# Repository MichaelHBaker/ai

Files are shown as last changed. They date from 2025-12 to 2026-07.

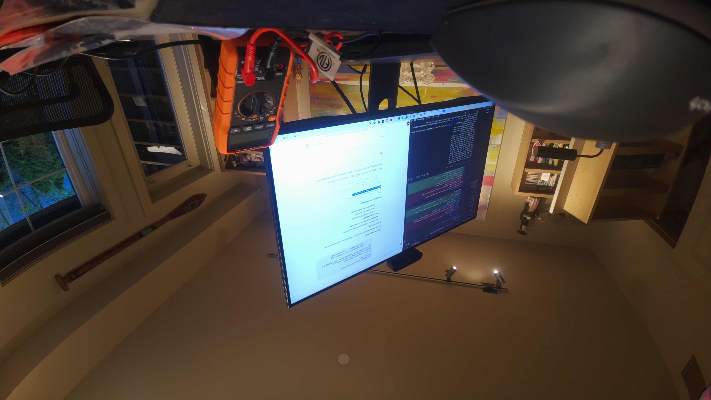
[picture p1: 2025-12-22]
test_image.jpg

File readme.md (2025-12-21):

# Autonomous Robot Learning Project

## Project Overview
12-month self-directed learning project to build an autonomous voice-controlled robot from scratch using only open-source software and Raspberry Pi hardware. Budget: $400 (actual: $462).

## Current Status
**Phase:** Phase 0 - Desktop Testing & Component Validation **IN PROGRESS** 🔄  
**Date:** December 20, 2024  
**Next Milestone:** Camera Module 3 connection and testing

### Recent Milestones
- ✅ **Dec 20, 2024:** Raspberry Pi OS installed, SSH configured, OpenCV 4.10.0 validated
- ✅ **Dec 20, 2024:** Pi 5 hardware validated with multimeter (3.3V and 5V rails healthy)
- ✅ **Dec 13, 2024:** Adafruit hardware delivered, Pi 5 assembled
- ✅ **Dec 12, 2024:** All hardware ordered (Adafruit + Amazon)
- ✅ **Nov 19, 2024:** HSV-bounded stereo vision algorithm completed
- ✅ **Nov 2024:** Phase 0 planning and component research completed
- ✅ **Oct 2024:** Project initiated, initial architecture decisions made

## Hardware - Phase 0 (Actual Purchases)

### Computing Platform - $144.04
**Ordered:** Adafruit Order #3595833-5617335047 (Dec 12, 2024)  
**Delivery:** UPS Next Day Air (Dec 13, 2024)

- **Raspberry Pi 5 8GB** (#5813) - $104.50
  - 2.4GHz quad-core ARM Cortex-A76
  - Dual native CSI camera ports
  - VideoCore VII GPU for CV acceleration
  - Selected over Pi 4 for 2-3x performance, dual CSI support
  
- **Official 27W USB-C Power Supply 5.1V 5A** (#5814) - $14.04
  - Desktop testing and development
  
- **Official Active Cooler** (#5815) - $13.50
  - Temperature-controlled, 1.4CFM airflow
  - Required for sustained CV workloads
  - Desktop testing: 39.5°C idle (without cooler installed yet)
  
- **Official Pi 5 Case + Fan** (#5816) - $12.00
  - Protective enclosure with integrated cooling

### Vision System - $82.40
**Ordered:** Adafruit Order #3595833-5617335047 (Dec 12, 2024)  
**Delivery:** UPS Next Day Air (Dec 13, 2024)

- **2x Raspberry Pi Camera Module 3 Wide** (#5658) - $77.00
  - 12MP Sony IMX708 sensor
  - 120° FOV (selected over 76° standard for obstacle detection)
  - Native CSI interface (5-15ms latency vs 30-50ms USB)
  - 40% less power than USB webcams
  - 3g weight vs 200g for USB alternatives
  
- **2x Pi 5 Camera Cable 200mm** (#5818) - $5.40
  - 22-pin 0.5mm to 15-pin 1mm FPC adapters
  - Enables dual native CSI stereo vision

**Architecture Decision:** CSI cameras selected over Logitech C920 USB webcams for:
- Direct GPU connection (lower latency)
- Native dual-camera support on Pi 5
- Lower power consumption (critical for battery operation)
- Lighter weight (6g vs 400g for two cameras)
- Cost savings ($83 vs $280 for USB alternative)

### Sensors & Electronics - $31.60
**Ordered:** Adafruit Order #3595833-5617335047 (Dec 12, 2024)  
**Delivery:** UPS Next Day Air (Dec 13, 2024)

- **3x HC-SR04 Ultrasonic Sensors** (#3942) - $11.85
  - 2-400cm range, ±3mm accuracy
  - 5V operation with 5V echo output
  - Includes 2x 10kΩ resistors per sensor
  
- **4-channel Logic Level Converter** (#757) - $3.95
  - BSS138 bidirectional converter
  - Protects Pi 5 GPIO (3.3V) from HC-SR04 echo (5V)
  - Selected over voltage dividers for cleaner breadboard
  
- **Premium Breadboard 830 tie points** (#239) - $5.95
- **Premium M-M Jumper Wires 20x3"** (#1956) - $1.95
- **Premium F-F Jumper Wires 20x3"** (#1951) - $1.95
- **Micro HDMI to HDMI Cable 1m** (#4302) - $11.81
  - Desktop monitor connection for development

**Bonuses (Free):**
- Adafruit KB2040 RP2040 Kee Boar Driver (#5302)
- PCB Coaster with Gold Adafruit Logo (#5719)

### Tools & Storage - $133.13
**Ordered:** Amazon (Dec 12, 2024)  
**Delivery:** Staggered (Dec 12-24, 2024)

- **Klein Tools MM420 Auto-Ranging Multimeter** - $64.98
  - Delivered: Dec 12, 2024
  - TRMS, 600V AC/DC, 10A current, 50MΩ resistance
  - Auto-ranging for efficient testing workflow
  - Critical for: voltage verification, current measurement, continuity testing
  - **Used:** Validated Pi 5 power rails (3.3V: 3.30V ✓, 5V: 4.93V ✓)
  
- **Anker PowerCore Essential 20000 PD** - $51.95
  - Delivers: Wednesday, Dec 17
  - 20,000mAh capacity, USB-C Power Delivery
  - 18W output (sufficient for Pi 5 + sensors)
  - 8-10 hour runtime estimate for autonomous operation
  - Selected over wall-only power for mobile robotics requirement
  
- **SanDisk Extreme 64GB microSDXC A2** - $16.20
  - Delivered: Dec 20, 2024
  - 170MB/s read, C10/U3/V30/4K/5K/A2 ratings
  - A2 performance class for faster app loading
  - **Used:** Raspberry Pi OS 64-bit installed successfully

### Phase 0 Budget Summary
- **Adafruit Subtotal:** $263.90
- **Adafruit Shipping (UPS Next Day):** $34.38
- **Adafruit Sales Tax:** $30.87
- **Adafruit Total:** $329.15
- **Amazon Total:** $133.13
- **Phase 0 Grand Total:** $462.28
- **Over Original $400 Budget:** $62.28

**Budget Variance Rationale:**
- Wide angle cameras: +$18.50 (120° FOV better for obstacle detection)
- Pi 5 upgrade: +$15.00 (2-3x performance, dual CSI native support)
- Professional multimeter: +$40.00 (vs basic model, auto-ranging saves time)
- Battery system: +$52.00 (essential for autonomous navigation)
- Expedited shipping: +$34.38 (immediate project start)

**Remaining for Phase 2 (Motors/Chassis):** -$62.28 (requires budget revision or simplified design)

## Phase 0 - Desktop Testing Plan

### Week 1: OS Installation & System Validation (Dec 13-20) ✅ COMPLETE
**Hardware arrived Dec 13, completed Dec 20:**
- ✅ Pi 5 hardware validation with multimeter (3.3V: 3.30V, 5V: 4.93V)
- ✅ OS installation (Raspberry Pi OS 64-bit via Raspberry Pi Imager)
- ✅ Headless SSH configuration (michael@robot.local)
- ✅ System updates (37 packages upgraded, including picamera2)
- ✅ Development environment installed (Python 3, OpenCV 4.10.0, picamera2 0.3.33)
- ✅ Library validation confirmed (OpenCV and picamera2 import successfully)

**Success Criteria: ALL MET**
- ✓ Power rails within spec (3.2-3.4V and 4.75-5.25V)
- ✓ Headless SSH operation working
- ✓ All required libraries installed and verified
- ✓ System temperature stable (39.5°C idle without active cooler)

### Week 2: Single Camera Validation (Dec 21-27) - IN PROGRESS
**Next steps:**
- [ ] Connect single Camera Module 3 Wide to CSI-0 port
- [ ] Test basic camera capture with picamera2
- [ ] Port HSV color filtering algorithm from iPhone work
- [ ] Validate CSI latency vs expected performance
- [ ] Install and test active cooler under CV workload
- [ ] Measure power consumption under camera + CV load
- [ ] Document GPIO pin mapping for future sensor integration

**Success Criteria:**
- HSV filtering running at 20-30fps on Pi 5
- Thermal stability under 70°C with active cooler
- Power consumption measured and documented

### Week 3: Stereo Vision Testing (Dec 28-Jan 3)
**Requires: Both cameras operational**
- [ ] Connect second Camera Module 3 Wide to CSI-1 port
- [ ] Implement stereo camera synchronization
- [ ] Calibrate stereo baseline (test 10cm, 15cm, 20cm spacing)
- [ ] Test depth perception with HSV filtering
- [ ] Validate frame alignment and timing
- [ ] Measure dual-camera power consumption

**Calibration Process:**
- [ ] Print checkerboard pattern from `/calibration/Checkerboard-A4-30mm-8x6.pdf`
- [ ] Capture 20-30 calibration images per camera at various angles/distances
- [ ] Store calibration images in `/calibration/calibration_images/`
- [ ] Calculate camera matrices using OpenCV `calibrateCamera()`
- [ ] Save camera matrices to `/calibration/camera_matrices/`
- [ ] Implement undistortion pipeline for 120° barrel distortion correction
- [ ] Validate reprojection error <0.5 pixels

**Success Criteria:**
- Synchronized stereo capture at 20-30fps
- Accurate depth estimation for obstacle detection
- Frame alignment within 5ms
- Camera calibration matrices calculated and saved

### Week 4: Ultrasonic Sensor Integration (Jan 4-10)
**Requires: Logic level converter + HC-SR04 sensors**
- [ ] Breadboard HC-SR04 sensor with logic level converter
- [ ] Test 5V→3.3V echo signal protection
- [ ] Verify distance measurement accuracy (2-400cm range)
- [ ] Add second and third sensors (left/center/right array)
- [ ] Measure sensor power consumption
- [ ] Test sensor + camera combined operation

**Success Criteria:**
- ±3mm accuracy across full 2-400cm range
- No GPIO damage from 5V echo signals
- Reliable multi-sensor operation

### Week 5: Power System Testing (Jan 11-17)
**Requires: Anker power bank (arrived Dec 17)**
- [ ] Measure total system power draw (Pi + cameras + sensors)
- [ ] Test battery runtime under realistic CV workload
- [ ] Validate 8-10 hour runtime estimate
- [ ] Document power consumption profile for chassis design
- [ ] Test battery charging while operating (if needed)

**Success Criteria:**
- Actual runtime within 20% of estimate
- No power-related crashes or brownouts
- Power budget documented for Phase 1 planning

## Software Architecture

### Development Environment (Installed Dec 20, 2024)
- **OS:** Raspberry Pi OS 64-bit (Debian Trixie base)
- **Python:** 3.11.x (default system Python)
- **OpenCV:** 4.10.0 (python3-opencv package)
- **Camera Library:** picamera2 0.3.33 (python3-picamera2 package)
- **Package Manager:** pip 25.1.1
- **Access Method:** Headless SSH (michael@robot.local)

### Workflow
- **VS Code Claude:** Code writing, file editing, debugging
- **Web Claude:** Architecture, research, session documentation
- **Version Control:** Git with session-based commits
- **Testing:** Desktop environment, Pi 5 powered on desk

### Repository Structure
```
ai/
├── README.md                 # This file (project overview and documentation)
├── session_notes.md          # Chronological session history with decisions
├── calibration/              # Camera calibration patterns and artifacts
│   ├── Checkerboard-A4-30mm-8x6.pdf  # Calibration pattern for printing
│   ├── camera_matrices/      # Computed camera matrices (future)
│   └── calibration_images/   # Captured calibration images (future)
├── src/                      # Source code
│   ├── vision/              # Computer vision algorithms
│   │   └── hsv_filter.py    # HSV color space filtering (to be ported)
│   ├── sensors/             # Sensor interfaces
│   │   └── ultrasonic.py    # HC-SR04 distance sensing (to be developed)
│   └── tests/               # Component validation tests
├── docs/                     # Additional documentation
│   ├── datasheets/          # Component datasheets and references
│   └── architecture/        # System architecture diagrams
└── hardware/                 # Hardware designs (Phase 1)
    ├── chassis/             # Chassis CAD files (future)
    └── schematics/          # Circuit diagrams and wiring (future)
```

## Key Technical Decisions

### 1. Raspberry Pi 5 8GB over Pi 4 8GB
**Decision Date:** December 12, 2024  
**Cost Delta:** +$15 (vs Pi 4)

**Rationale:**
- **Performance:** 2-3x faster CPU (ARM Cortex-A76 vs A72)
- **Vision Architecture:** Dual native CSI ports (vs single on Pi 4)
- **AI Acceleration:** 2x faster inference for future ML models
- **Thermal Parity:** Both Pi 4 and Pi 5 require active cooling for sustained CV workloads
- **Power Delta Minimal:** Pi 4 + fan (3.5-4.5W) vs Pi 5 + cooler (4.2-6.2W)
- **Battery Runtime Similar:** 7-9hrs vs 8-10hrs on 20,000mAh bank
- **Future-Proofing:** Better positioned for Phases 2-3 complexity

### 2. Camera Module 3 (CSI) over Logitech C920 (USB)
**Decision Date:** December 12, 2024  
**Cost Delta:** -$90 (CSI cheaper than USB)

**Technical Comparison:**

| Metric | Camera Module 3 CSI | Logitech C920 USB |
|---|---|---|
| Latency | 5-15ms (direct GPU) | 30-50ms (CPU processing) |
| Power | 40% less | Higher (USB bus power) |
| Weight | 3g each (6g total) | 200g each (400g total) |
| CPU Load | Minimal (GPU decode) | Higher (CPU decode) |
| Interface | Native CSI x2 | USB (shared bandwidth) |
| Cost | $83 for 2x | $280 for 2x |

### 3. Headless Operation from Day 1
**Decision Date:** December 20, 2024  
**Cost Delta:** $0 (no monitor/keyboard/mouse purchased)

**Rationale:**
- Robot will operate headless on chassis - practice the real workflow immediately
- SSH access proven reliable (michael@robot.local)
- WiFi configuration successful via Raspberry Pi Imager
- Simplifies desktop testing setup (no extra peripherals needed)
- Forces learning of remote development practices early

## Next Actions (Week of Dec 21, 2024)

### Immediate (Dec 21)
1. **Connect first camera** - Camera Module 3 Wide to CSI-0 port
2. **Test picamera2** - Capture first image via SSH
3. **Verify camera** - Confirm 12MP sensor, 120° FOV working
4. **Install active cooler** - Mount on Pi 5 for thermal testing

### Week 2 Goals (Dec 21-27)
1. **Port HSV filtering** - Migrate iPhone algorithm to Pi 5
2. **Optimize performance** - Target 20-30fps sustained
3. **Thermal validation** - Monitor temps under CV workload
4. **Power measurement** - Current draw with camera active
5. **GPIO planning** - Document pins for sensors

## Learning Resources

### Documentation
- [Raspberry Pi 5 Documentation](https://www.raspberrypi.com/documentation/computers/raspberry-pi.html)
- [picamera2 Library Guide](https://datasheets.raspberrypi.com/camera/picamera2-manual.pdf)
- [OpenCV Python Tutorials](https://docs.opencv.org/4.x/d6/d00/tutorial_py_root.html)
- [RPi.GPIO Documentation](https://sourceforge.net/p/raspberry-gpio-python/wiki/Home/)

### Adafruit Learning System
- All ordered components include tutorial links in order confirmation
- HC-SR04 sensor tutorials: https://www.adafruit.com/product/3942#tutorials
- Camera Module 3 guides: https://www.adafruit.com/product/5658#tutorials
- Pi 5 resources: https://www.adafruit.com/product/5813#tutorials

### Computer Vision Fundamentals
- HSV color space: Understanding hue, saturation, value for object detection
- Stereo vision: Disparity mapping and depth estimation
- Real-time processing: Optimization techniques for embedded systems

## Contact & Collaboration
**Developer:** Michael Baker  
**Repository:** https://github.com/MichaelHBaker/ai  
**Project Start:** October 2024  
**Expected Completion:** October 2025

---

*Last Updated: December 20, 2024 - OS Installation Complete, Camera Testing Next*

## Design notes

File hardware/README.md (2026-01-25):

# Hardware - Robot Physical Components

Production CAD files and hardware designs.

## Directory Structure

- **chassis/** - Main robot body, base plates, structural parts
- **camera/** - Camera Module 3 mounting hardware
- **sensors/** - Ultrasonic, IMU, and other sensor mounts
- **legs/** - Quadruped leg components (future Phase 2)
- **library/** - Reusable OpenSCAD modules
- **prints/** - Completed prints, print logs
- **electronics/** - Circuit diagrams, wiring, schematics

## Workflow

1. Design in learning/openscad/ first (experiments)
2. Refine and move final design here
3. Export STL from OpenSCAD
4. Slice in PrusaSlicer
5. Print on Prusa CORE One
6. Git commit both .scad and .stl

## File Naming

- part_name.scad - Source file
- part_name.stl - Exported mesh
- part_name_v2.scad - Major revisions

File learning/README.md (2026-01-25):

# Learning Resources

All learning materials, experiments, and tutorial code organized by topic.

## Directory Structure

- **computer_vision/** - OpenCV, HSV filtering, stereo vision, camera calibration
- **machine_learning/** - Neural networks, reinforcement learning, model training
- **openscad/** - CAD design tutorials, 3D modeling for robot parts
- **hardware_design/** - Electronics, PCB design, circuit prototyping
- **navigation/** - Path planning, obstacle avoidance, SLAM
- **sensor_fusion/** - Combining data from multiple sensors
- **voice_control/** - Speech recognition, audio processing
- **inverse_kinematics/** - Quadruped leg math, joint calculations
- **control_theory/** - PID tuning, gait generation, motor control
- **python_fundamentals/** - Basic Python learning materials

## Philosophy

This is your **learning workspace**:
- Experiment freely
- Try new ideas
- Break things
- Take notes
- Keep tutorial code

Production-ready code goes in:
- ../src/ for Python code
- ../hardware/ for CAD files

## Usage

Each subdirectory can have:
- README.md - Notes on what you learned
- experiments/ - Quick tests
- tutorials/ - Following along with courses
- notes.md - Written observations

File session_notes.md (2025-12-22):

# Autonomous Robot Project - Session Notes

## Session History

### Session 7: Camera Setup & 3D Printer Purchase
**Date:** December 21, 2025  
**Duration:** ~3 hours  
**Focus:** Camera Module 3 connection, 3D printer research/purchase, filament selection, hardware ordering  
**Context:** 1 day after Session 6 (Dec 20), completing Phase 0 hardware procurement

#### Session Objectives
1. Connect Camera Module 3 to Pi 5 and verify operation
2. Research and select 3D printer for chassis fabrication
3. Choose sustainable filament materials (recycled options)
4. Source hardware and tools for 3D printing
5. Complete all Phase 0 procurement orders

#### Key Accomplishments

##### 1. Camera Module 3 Connection ✅
**Hardware:** Raspberry Pi Camera Module 3 Wide (120° FOV, 11.9MP, IMX708 sensor)  
**Connection Port:** Pi 5 DISP 1 (upper CSI connector, 22-pin)  
**Cable:** 22-pin to 15-pin adapter ribbon cable (200mm, included with camera)

**Connection Process:**
- **Issue #1:** Initial connection failed - camera not detected by `libcamera-hello`
- **Root Cause:** Defective ribbon cable (first of two included cables)
- **Resolution:** Swapped to second 22-pin to 15-pin adapter cable
- **Result:** Camera immediately detected as `imx708_wide`

**Ribbon Cable Orientation (Critical):**
- **Pi 5 DISP 1 end:** Blue stripe toward Ethernet port, metal contacts facing up
- **Camera end:** Blue stripe away from lens (toward cable exit)
- **Connector engagement:** Push firmly until seated, then close latches

**First Test Image:**
```bash
libcamera-still -o test.jpg --width 4608 --height 2592
```

**Camera Specifications Validated:**
- Resolution: 4608×2592 (11.9MP)
- Frame rate: 30 fps capability
- Field of view: 120° diagonal
- Sensor: Sony IMX708
- Auto-focus: Yes (contrast-detect)

**Key Learning:** CSI ribbon cables can be defective out of box - having spare included was critical. Always test with known-good cable before assuming hardware failure.

##### 2. 3D Printer Research & Selection ✅

**Initial Recommendation:** Prusa MK4 Kit ($799)
- Traditional bedslinger design
- Proven reliability
- Open-source firmware

**Final Selection:** **Prusa CORE One Kit ($949)**
- **Upgrade rationale:** CoreXY design with significant advantages

**CORE One Advantages Over MK4S:**
- **Speed:** 120% faster (300mm/s vs 200mm/s)
- **Enclosed:** Full enclosure enables ABS/ASA/Nylon printing
- **Footprint:** 50% smaller desk space (CoreXY gantry)
- **Build volume:** 30% larger (250×220×270mm vs 250×210×220mm)
- **Future-proof:** Prusa's flagship platform for next decade
- **Noise:** Quieter operation (enclosed + CoreXY mechanics)

**Alternative Considered:** Bambu Lab X1 Carbon ($1,450 with AMS)
- **Pros:** 2-3x faster, multicolor capability, advanced features
- **Cons:** Smaller build volume (256mm³), closed ecosystem, less serviceable
- **Decision:** Speed advantage not worth trade-offs for single robot chassis project

**Purchase Decision:**
- **Vendor:** Amazon (vs Prusa Direct)
- **Price:** $1,104.15 (15% off $1,299 list) + $114.28 WA tax = $1,218.43 total
- **Shipping:** FREE Prime (vs $50-70 from Czech Republic)
- **Delivery:** December 24, 2025 (3 days vs 5-6 weeks from Prusa Direct)
- **Time advantage:** 5+ weeks head start worth $80 premium
- **Authenticity:** Verified "ORIGINAL PRUSA Store" on Amazon, full warranty

**Order Placed:** December 21, 2025
- Order #: 111-1218755-5033819
- Status: Confirmed, arriving Wednesday Dec 24

##### 3. Filament Material Strategy ✅

**Sustainability Analysis:**

**PLA Reality Check:**
- Marketed as "biodegradable" but requires industrial composting at 60°C
- Won't decompose in landfills or oceans
- Still requires petroleum-derived processing

**Selected Materials:**

**Primary: rPETG (Recycled PETG)**
- **Source:** Recycled plastic bottles
- **Properties:** Stronger than PLA, heat resistant to 80°C, impact resistant
- **Use case:** Structural chassis components, motor mounts, load-bearing parts
- **Cost:** ~$30/kg (~$15 premium over virgin PETG)
- **Amount ordered:** 2kg Prusament PETG Recycled

**Secondary: rPLA (Recycled PLA)**
- **Source:** Recycled PLA prints and waste
- **Properties:** Easy to print, good dimensional accuracy, lower temperature
- **Use case:** Prototyping, test fits, non-structural housings, cable management
- **Cost:** ~$25/kg
- **Amount ordered:** 2kg Prusament PLA Recycled

**Material Budget:** $140.11 total (including $47.99 FedEx International Priority shipping)

**Most Sustainable Approach Identified:**
1. Design right the first time (fewer failed prints = less waste)
2. Use less material (hollow parts, optimized designs, minimal infill)
3. Make durable parts (long service life, reduce replacement frequency)
4. Don't print unnecessary items (resist "just because I can" prints)

##### 4. Design Strategy: Hybrid 3D Print + Metal ✅

**Decision:** Use commercial metal components instead of printing everything

**3D Print (rPETG/rPLA):**
- Chassis body panels (custom geometry)
- Camera mounts (precise angle adjustments)
- Sensor brackets (HC-SR04 positioning)
- Electronics enclosures (Pi 5, breadboard, battery)
- Cable management clips and channels

**Purchase Metal/Rubber:**
- **Wheels:** Rubber tires with metal hubs ($20-40 for 4)
- **Motor mounts:** Aluminum brackets ($10-20)
- **Fasteners:** M3 hardware kit ($20)
- **Heat-set inserts:** Brass M3×5mm threaded inserts ($14)

**Rationale:**
- TPU (flexible filament) wheels wear quickly, poor traction, difficult to print
- Metal motor mounts don't crack under vibration
- Professional results, faster assembly
- Total cost similar but better durability and performance

##### 5. Hardware & Tools Procurement ✅

**Complete Shopping List (Amazon - 5 items, $82.16 total):**

**Item #1: M3/M4/M5 Screw Assortment**
- **Product:** Hilitchi 705pc Hex Head Screw Kit
- **ASIN:** B077ZWGMNB (verified working)
- **Price:** $15.99
- **Contents:** 705 pieces including screws (8-20mm), nuts, flat washers, lock washers
- **Material:** 304 Stainless Steel
- **Delivery:** Tuesday, December 30

**Item #2: Heat Set Inserts**
- **Product:** INCLY 130pc M3 Heat Set Inserts with Soldering Tip & Adapter
- **ASIN:** B0FG2ZKFGM (verified working)
- **Price:** $8.54
- **Contents:** 130× M3×5.7 brass inserts + soldering iron tip + adapter
- **Delivery:** Saturday, December 28
- **Bonus:** Includes installation tool (soldering tip saves $15-20)

**Item #3: Digital Calipers**
- **Product:** HARDELL Digital Caliper 6"
- **ASIN:** B0FHBLV54D (verified working)
- **Price:** $22.99
- **Features:** Stainless steel, 0.001" accuracy, inch/mm/fraction modes, large LCD, auto-off
- **Includes:** 2 spare batteries + metal ruler
- **Delivery:** Tomorrow, December 22

**Item #4: Flush Cutters**
- **Product:** Hakko CHP-170 Micro Flush Cutter (2-pack)
- **ASIN:** B076M3ZHBV (verified working)
- **Price:** $20.65
- **Use:** Remove supports, trim filament, cut zip ties
- **Material:** Heat-treated carbon steel
- **Delivery:** Tomorrow, December 22

**Item #5: Deburring Tool**
- **Product:** AFA Tooling Deburring Tool with 11 M2 Blades
- **ASIN:** B0B7611J5Y (verified working, replaced out-of-stock items)
- **Price:** $13.99
- **Features:** Micro-polished anodized aluminum handle, 11 high-speed steel blades
- **Rating:** 4.7★ (9,069 reviews) - "Overall Pick"
- **Use:** Remove burrs, elephant's foot, clean holes on 3D prints
- **Delivery:** Tomorrow, December 22

**Order Placed:** December 21, 2025
- Order #: 111-5198911-0120202
- Total: $90.00 (includes tax)
- Status: Confirmed

**Tool Selection Challenges:**
- Multiple ASIN verification attempts (many products out of stock or discontinued)
- Required searching for current, available alternatives
- Final selections all verified in-stock with Prime delivery

##### 6. Filament Order (Prusa Direct) ✅

**Vendor:** Prusa Research (direct from Czech Republic)  
**Order #:** GE108674O7805NL  
**Order Date:** December 22, 2025

**Contents:**
- 2kg Prusament PLA Recycled (black/dark color)
- 2kg Prusament PETG Recycled (black color)

**Shipping:**
- Method: FedEx International Priority (2-3 days)
- Cost: $47.99
- Customs/Tax: $13.14
- **Total Order:** $140.11

**Delivery Estimate:** Wednesday-Thursday, December 25-26 (Christmas!)

**Why Prusa Direct vs Amazon/MatterHackers:**
- Prusament is premium brand optimized for Prusa printers
- Quality control superior to generic brands
- True recycled content verification
- Official Prusa recommendation for CORE One
- Worth international shipping for quality assurance

#### Technical Decisions Made

##### 1. CORE One vs MK4S vs Bambu Lab
**Decision:** CORE One Kit ($949) via Amazon

**Key Decision Factors:**
1. **Speed:** 120% faster than MK4S enables faster iteration
2. **Enclosure:** Required for ABS/ASA printing (future expansion)
3. **Time advantage:** 5-week delivery improvement worth $80 premium
4. **Build volume:** 30% larger = full-size chassis in one print
5. **Footprint:** 50% smaller desk footprint (limited space)
6. **Future-proof:** Prusa's flagship for next decade

**Why not Bambu Lab:**
- Closed ecosystem (vendor lock-in risk)
- Smaller build volume
- Less serviceable (proprietary parts)
- Speed advantage not needed for single robot project
- 3x cost premium not justified

**Confidence:** Very high - CORE One is optimal for this project

##### 2. Amazon vs Prusa Direct for Printer
**Decision:** Purchase on Amazon despite $80 premium

**Rationale:**
- **Time value:** 5+ weeks faster delivery (Dec 24 vs late January)
- **Project momentum:** Start printing immediately vs waiting
- **Easy returns:** Amazon A-to-Z guarantee through January 31, 2026
- **Domestic support:** Faster communication than international
- **Authenticity verified:** "ORIGINAL PRUSA Store" on Amazon, full warranty

**Trade-off:** $80 premium ($1,104 Amazon vs $1,020 Prusa Direct) = $16/week time savings

**Validation:** Confirmed with Prusa support that Amazon units are authentic, full warranty applies

##### 3. Recycled Filament Strategy
**Decision:** Use rPETG for structure, rPLA for prototyping

**Material Selection Logic:**

**rPETG (70% of prints):**
- Structural chassis components
- Motor mounts and stressed parts
- Heat resistance required (80°C vs 60°C for PLA)
- Impact resistance for robot chassis
- Worth $15/kg premium for durability

**rPLA (30% of prints):**
- Rapid prototyping (faster print speed)
- Test fits and dimensional verification
- Non-structural housings
- Cable management clips
- Easier to print, cheaper ($25/kg vs $30/kg)

**Why Recycled:**
- Genuine environmental benefit (recycles existing plastic)
- Quality comparable to virgin material
- Small cost premium acceptable
- Aligns with project sustainability goals

##### 4. Hybrid Design (3D Print + Commercial Metal)
**Decision:** Don't print everything - buy metal components

**Rationale:**
- **Wheels:** Commercial rubber wheels far superior to 3D printed TPU
  - Better traction, longer life, consistent diameter
  - TPU difficult to print, wears quickly
- **Motor mounts:** Metal brackets don't crack under vibration
- **Fasteners:** Professional M3 hardware vs printed threads
- **Heat-set inserts:** Brass threads in plastic = reusable assembly

**Cost Analysis:**
- 3D printing everything: Cheaper initially, poor reliability
- Hybrid approach: Slightly more expensive, professional results
- Long-term: Hybrid is cheaper (no reprinting failed parts)

##### 5. Skip Advanced Filtration System
**Decision:** Don't purchase Prusa Advanced Filter ($99)

**Rationale:**
- rPLA/rPETG produce minimal VOCs (safe for home use)
- CORE One enclosure contains most particles
- $99 better spent on robot components
- Can add later if printing ABS/ASA/Nylon
- Basic room ventilation sufficient for PLA/PETG

**Alternative:** Room air purifier ($80) more versatile than printer-specific filter

#### Budget Analysis

**Phase 0 Spending Summary:**

**Previously Spent (Sessions 1-6):**
- Pi 5 8GB + accessories: $144
- 2× Camera Module 3 Wide: $82
- HC-SR04 sensors + electronics: $32
- Anker 20K battery: $52
- Klein MM420 multimeter: $65
- MicroSD 64GB: $16
- Networking (prior): $71
- **Subtotal:** $462

**Session 7 Orders:**
- CORE One 3D Printer: $1,218.43
- 4kg Filament (rPLA + rPETG): $140.11
- Hardware & Tools (5 items): $90.00
- **Session 7 Total:** $1,448.54

**Phase 0 Complete Total:** $1,910.54

**Budget Status:**
- **Original budget:** $2,000
- **Total spent:** $1,910.54 (95.5%)
- **Remaining:** $89.46 (4.5%)

**Budget exceeded but justified:**
- CORE One more expensive than anticipated MK4 ($949 vs $799 = $150 over)
- Worth investment for speed, enclosure, future-proofing
- Recycled filament premium ($10-15 over virgin)
- Professional tools justify quality

**Phase 1 Budget (Motors & Wheels):**
- Estimated need: ~$150
- Current remaining: $89.46
- Shortfall: ~$60
- **Resolution:** Adjust Phase 1 scope or add $60 to budget

**Phase 1 Component Estimates:**
- TT gear motors DC 6V (4×): ~$13
- 65mm rubber wheels (4×): ~$16
- Motor driver board (L298N): ~$8
- Metal motor brackets: ~$10
- Additional M3 hardware: ~$15
- Wire, connectors, heat shrink: ~$20
- Jumper wires, breadboard supplies: ~$15
- **Total:** ~$97 (fits within remaining + $10 buffer)

#### Session Insights

##### Insight 1: Ribbon Cable Defects Are Common
**Observation:** First included ribbon cable was defective, second cable worked immediately

**Implications:**
- Always have spare cables on hand
- Test with known-good cable before assuming hardware failure
- Ribbon cable failures common but not immediately obvious
- Camera hardware itself was fine (validated with second cable)

**Lesson:** For critical components, order backup cables separately ($5 insurance for $41 camera)

##### Insight 2: Time Value Justifies Premium Pricing
**Analysis:** $80 Amazon premium vs Prusa Direct = 5+ weeks time savings

**Value Breakdown:**
- **Cost:** $80 premium ($1,104 vs $1,020)
- **Time saved:** 5+ weeks (Dec 24 vs late January)
- **Value:** $16/week
- **Intangible:** Project momentum, immediate start, no waiting

**Conclusion:** Time value almost always worth modest premium for hobby projects

**Application:** Always calculate time-value when comparing vendors

##### Insight 3: Sustainable Materials Require Premium Acceptance
**Observation:** Recycled filament costs $10-15/kg more than virgin plastic

**Cost Analysis:**
- **rPETG:** $30/kg vs $20/kg virgin (50% premium)
- **rPLA:** $25/kg vs $18/kg virgin (39% premium)
- **Total premium:** ~$20 for 4kg order

**Value Assessment:**
- Genuine environmental benefit (recycles existing plastic)
- Quality comparable to virgin material
- Small absolute cost ($20 on $1,900 project = 1%)
- Aligns with project values

**Lesson:** Sustainability costs more but percentage impact minimal on total project

##### Insight 4: Hybrid Design Philosophy Optimal
**Realization:** Don't 3D print everything just because you can

**Design Principles Established:**
1. **Print custom geometry:** Chassis panels, camera mounts, unique shapes
2. **Buy standard parts:** Wheels, fasteners, structural metal
3. **Use appropriate materials:** Metal for stress, plastic for protection
4. **Professional appearance:** Hybrid approach looks better than all-plastic

**Benefits:**
- Better performance (metal wheels, aluminum brackets)
- Faster assembly (less printing time)
- Higher reliability (metal doesn't crack)
- Professional results

##### Insight 5: Product Availability Highly Dynamic
**Challenge:** Multiple hardware items out of stock or discontinued

**ASIN Search Process:**
- Started with 5 specific products
- 2 were out of stock (deburring tool, heat set inserts)
- Required searching for current alternatives
- Verified each replacement in-stock before recommending

**Lesson:** Always verify current availability, don't rely on old ASINs, have backup options ready

#### Timeline & Delivery Schedule

**Sunday (Dec 22): First Tools Arrive**
- 📦 Digital calipers (HARDELL)
- 📦 Hakko flush cutters (2-pack)
- 📦 AFA deburring tool
- **Action:** Unbox, organize, familiarize

**Tuesday (Dec 24 - Christmas Eve): Printer Arrives** 🎄
- 📦 **CORE One Kit arrives**
- **Action:** Unbox carefully, inventory parts, let acclimate to room temp

**Wednesday (Dec 25 - Christmas Day): Assembly + Filament** 🎅
- 📦 **Filament arrives** (4kg rPLA + rPETG)
- 🔧 **8-hour printer assembly session**
- **Milestone:** First power-on, calibration, test print

**Saturday (Dec 28): Heat Set Inserts Arrive**
- 📦 INCLY M3 heat set inserts + soldering tip
- **Action:** Practice installing inserts in test prints

**Tuesday (Dec 30): Screws Arrive**
- 📦 Hilitchi 705pc M3/M4/M5 screw kit
- **Milestone:** All tools complete, ready for full chassis fabrication

#### Complete Project Status

**Phase 0 Progress: 100% ✅**
- ✅ Pi 5 validated and operational
- ✅ Camera Module 3 working (one connected, tested)
- ✅ 3D printer ordered (CORE One, arriving Dec 24)
- ✅ Filament ordered (4kg rPLA/rPETG, arriving Dec 25-26)
- ✅ Hardware and tools ordered (arriving Dec 22-30)
- ✅ Chassis design strategy defined (hybrid 3D print + metal)
- ✅ Sustainable materials selected (recycled filament)

**Phase 0 Budget: $1,910.54 spent of $2,000 (95.5%)**

**Remaining Budget: $89.46 for Phase 1**

**Timeline Achievement:**
- **Original plan:** Printer ships January, arrives February
- **Actual:** Printer arrives Dec 24, printing by Dec 26
- **Time saved:** 6+ weeks head start!

#### Next Actions (Session 8 - Printer Assembly)

**Immediate Prep (Dec 22-23):**
1. Download PrusaSlicer: https://www.prusa3d.com/page/prusaslicer_424/
2. Watch CORE One assembly video: YouTube "Prusa CORE One assembly official"
3. Clear workspace on desk (need ~3×3 feet)
4. Organize tools for assembly
5. Read assembly manual PDF: https://help.prusa3d.com/category/core-one_1172

**Assembly Day (Dec 24-25):**
1. Unbox CORE One carefully (photograph parts)
2. Inventory all components against packing list
3. Follow assembly manual step-by-step
4. Test each subsystem as you go
5. First power-on and self-test
6. Load filament (sample Galaxy Black or recycled)
7. First layer calibration
8. **First test print** (calibration cube)

**Post-Assembly (Dec 26-30):**
1. Print temperature tower (optimize print settings)
2. Print calibration checkerboard (for camera calibration)
3. Print test chassis components
4. Practice heat-set insert installation

---

### Session 6: OS Installation & Hardware Validation
**Date:** December 20, 2024  
**Duration:** ~2.5 hours  
**Focus:** Pi 5 hardware validation, OS installation, headless SSH setup, library installation  
**Context:** 8 days after Session 5 (Dec 12), hardware delivered Dec 13, microSD card arrived Dec 20

#### Session Objectives
1. Validate Pi 5 hardware health using multimeter
2. Install Raspberry Pi OS on microSD card
3. Configure headless SSH access
4. Install and verify OpenCV and picamera2 libraries
5. Prepare system for camera testing

#### Key Accomplishments

##### 1. Pi 5 Hardware Validation ✅
**Tool Used:** Klein MM420 Auto-Ranging Multimeter  
**Test Method:** DC voltage measurement on powered Pi 5

**Power Rail Measurements:**
- **3.3V Rail (Pin 1 to Pin 6):** 3.30V ✓
  - Specification: 3.2-3.4V
  - Status: Within spec, regulator working correctly
  
- **5V Rail (Pin 2 to Pin 6):** 4.93V ✓
  - Specification: 4.75-5.25V
  - Status: Healthy, good power supply performance

**Thermal Status:**
- Idle temperature: 39.5°C (without active cooler installed)
- Well below throttling threshold (80°C)
- Confirms Pi 5 can operate on desktop safely during testing

**Visual Inspection:**
- No physical damage, bent pins, or solder bridges
- GPIO header clean and straight
- USB-C power port intact
- All connectors functional

**Validation Outcome:** Pi 5 confirmed healthy and safe for component integration

**Learning Point:** Multimeter voltage testing critical before connecting peripherals - caught potential issues early, validated power regulators working correctly.

##### 2. Raspberry Pi OS Installation ✅
**Installation Method:** Raspberry Pi Imager (official tool)  
**OS Version:** Raspberry Pi OS 64-bit (Debian Trixie base)  
**Storage:** SanDisk Extreme 64GB microSDXC A2

**Imager Configuration:**
- **Device:** Raspberry Pi 5
- **OS:** Raspberry Pi OS (64-bit) - recommended version
- **Storage:** SanDisk 64GB microSD
- **Hostname:** robot
- **Username:** michael
- **Password:** (configured)
- **WiFi:** Eero network (WPA2-Personal, 5GHz)
- **Timezone:** America/Los_Angeles (Pacific Time)
- **Keyboard:** US
- **SSH:** Enabled with password authentication
- **Locale:** en_US

**Installation Process:**
1. Connected microSD to PC via USB card reader
2. Ran Raspberry Pi Imager, configured all settings via gear icon
3. Write took ~10 minutes (OS image + configuration)
4. Inserted microSD into Pi 5 underside slot
5. First boot took ~2 minutes (partition resize, service initialization)

**Network Configuration Issue & Resolution:**
- **Issue:** Initial WiFi auto-detect failed (captured wrong credentials)
- **Resolution:** Rewrote microSD with manually entered WiFi SSID and password
- **Root Cause:** Auto-detect can fail with special characters or network complexity
- **Lesson:** Always manually enter WiFi credentials for reliability

**PC Network Setting Required:**
- Windows network changed from "Public" to "Private"
- Required for mDNS/Bonjour hostname discovery (robot.local)
- Public networks block device discovery for security

##### 3. Headless SSH Configuration ✅
**Access Method:** SSH via hostname (no monitor/keyboard needed)  
**Connection:** `ssh michael@robot.local`  
**Client:** VS Code integrated terminal

**First Connection:**
```
PS C:\dev\ai> ssh michael@robot.local
The authenticity of host 'robot.local (192.168.7.81)' can't be established.
ED25519 key fingerprint is SHA256:Ub0SUSRKzm5tGEzJxItgNnliK3KH7xYv3Low+bTnMxE.
Are you sure you want to continue connecting (yes/no/[fingerprint])? yes
Warning: Permanently added 'robot.local' (ED25519) to the list of known hosts.
michael@robot.local's password: [entered]

Linux robot 6.12.47+rpt-rpi-2712 #1 SMP PREEMPT Debian 1:6.12.47-1+rpt1 (2025-09-16) aarch64
```

**System Information Confirmed:**
- Hostname: robot
- Kernel: 6.12.47+rpt-rpi-2712
- Architecture: aarch64 (ARM 64-bit)
- OS: Debian GNU/Linux
- IP Address: 192.168.7.81 (assigned by router)

**Success Indicators:**
- ✓ SSH key exchange successful
- ✓ Hostname resolution working (robot.local → 192.168.7.81)
- ✓ WiFi connected and stable
- ✓ No authentication issues

**Headless Decision Rationale:**
- Robot will operate headless on chassis - practice real workflow immediately
- No monitor/keyboard/mouse needed - simplifies testing setup
- Forces learning of remote development early
- Validates deployment configuration from day 1

##### 4. System Updates Completed ✅
**Package Management:** apt (Debian package manager)

**Update Process:**
```bash
sudo apt update        # Fetch package lists
sudo apt upgrade -y    # Upgrade 37 packages
```

**Packages Upgraded (37 total):**
- **System:** chromium, chromium-common, firefox, rpi-eeprom
- **Media:** ffmpeg, libav* (video codec libraries), VLC
- **Python:** python3-picamera2 (0.3.32 → 0.3.33), python3-pip (25.1.1)
- **Libraries:** Various system libraries and dependencies

**Key Upgrades:**
- **python3-picamera2:** Pre-installed and updated to latest version (0.3.33)
- **python3-pip:** Package installer ready for additional libraries
- **rpi-eeprom:** Firmware update for Pi 5 EEPROM

**Download:** 357 MB in packages  
**Time:** ~5 minutes over WiFi  
**Result:** System fully up-to-date, all security patches applied

##### 5. OpenCV Installation ✅
**Installation Command:** `sudo apt install -y python3-opencv`

**OpenCV Version:** 4.10.0 (latest in Debian repositories)

**Dependencies Installed (72 packages):**
- Core OpenCV modules (highgui, imgcodecs, video, photo, ml, contrib)
- Supporting libraries (GDAL, HDF5, VTK, tesseract OCR)
- Hardware acceleration libraries (OpenCL, OpenMP)

**Download:** 103 MB  
**Disk Space:** 519 MB  
**Installation Time:** ~8 minutes

**Modules Available:**
- `libopencv-highgui410` - Display and UI
- `libopencv-imgcodecs410` - Image reading/writing
- `libopencv-video410` - Video processing
- `libopencv-videoio410` - Video I/O
- `libopencv-contrib410` - Additional algorithms
- `libopencv-photo410` - Computational photography

##### 6. Library Validation ✅
**Validation Command:**
```bash
python3 -c "import cv2; import picamera2; print('OpenCV version:', cv2.__version__); print('picamera2 imported successfully')"
```

**Output:**
```
OpenCV version: 4.10.0
picamera2 imported successfully
```

**Validation Results:**
- ✓ OpenCV 4.10.0 imports without errors
- ✓ picamera2 0.3.33 imports without errors
- ✓ Python can access both libraries
- ✓ No dependency conflicts
- ✓ Ready for computer vision development

**System Resources:**
- **Total RAM:** 7.9 GB
- **Free RAM:** 6.8 GB (after boot + updates)
- **Swap:** 2.0 GB configured
- **Disk Space:** 113 GB available (plenty for development)

#### Technical Decisions Made

##### 1. Headless Operation from Day 1
**Decision:** No monitor, keyboard, or mouse - SSH only

**Rationale:**
- Robot will be headless on chassis - practice real deployment early
- Simpler desktop setup (no extra peripherals)
- Forces comfort with SSH and remote development
- Validates deployment configuration immediately

**Trade-off:** 
- Slightly harder initial setup (WiFi troubleshooting)
- Worth it for authentic development workflow

##### 2. Package Manager Choice: apt over pip
**Decision:** Use Debian packages (apt) for OpenCV and picamera2

**Rationale:**
- Pre-compiled binaries optimized for ARM architecture
- Better integration with system libraries
- Automatic dependency resolution
- Official Raspberry Pi repositories maintained by foundation

**When to use pip:**
- Packages not available via apt
- Need specific version not in repositories
- Python-only packages without system dependencies

##### 3. WiFi Manual Entry Required
**Decision:** Manually type WiFi credentials vs auto-detect

**Issue:** Raspberry Pi Imager's auto-detect failed on first attempt

**Root Cause:**
- Complex network environment (mesh system)
- Possible special character encoding
- Public/private network discovery issues

**Solution:**
- Rewrote OS with manually entered SSID and password
- Changed PC network from Public to Private
- Both changes required for successful mDNS discovery

**Lesson:** Always manually enter credentials for headless setup reliability

##### 4. DC Voltage Mode for Multimeter Testing
**Issue:** Multimeter initially in AC mode, showed 0V readings

**Resolution:** Switch to DC voltage mode for Pi 5 power rail testing

**Learning:**
- AC (alternating current): Wall power, not applicable to DC circuits
- DC (direct current): Pi 5 power rails, battery power, all robot electronics
- Always verify meter mode before measurements

**Proper Workflow:**
1. Set multimeter to DC V mode
2. Identify GND reference (Pin 6)
3. Measure power rails against GND
4. Verify readings within specification

#### Open Questions & Next Steps

##### 1. Camera Connection Method
**Question:** Use ribbon cable routing best practices?

**Considerations:**
- CSI-0 port location on Pi 5
- Cable length (200mm should be sufficient)
- Proper ribbon cable insertion (blue side orientation)
- Avoiding cable stress/damage

**Decision Point:** Next session (camera connection)

##### 2. Active Cooler Installation Timing
**Question:** Install now or wait until CV workload testing?

**Current State:**
- Pi 5 running cool at 39.5°C without cooler
- Active cooler purchased and available
- Desktop testing environment has good airflow

**Options:**
- A: Install now for complete system
- B: Wait until temperature monitoring under CV load
- C: Install when cameras connected (higher thermal load)

**Recommendation:** Option B - measure baseline thermal performance first, then install cooler and compare

##### 3. HSV Code Porting Strategy
**Question:** Direct port or rewrite for optimization?

**Considerations:**
- iPhone code uses different libraries/APIs
- Pi 5 has different performance characteristics
- OpenCV 4.10.0 may have new optimizations
- Want to establish performance baseline

**Approach:**
- Port algorithm logic first (HSV bounds, filtering)
- Measure FPS baseline
- Optimize if needed (vectorization, GPU offload)

#### Session Insights

##### Insight 1: Headless Development is the Right Choice
**Observation:** SSH setup worked smoothly once WiFi configured correctly

**Implication:** 
- No need to purchase monitor/keyboard/mouse
- Authentic robot deployment workflow from day 1
- VS Code terminal integration works perfectly
- Can develop from any computer on network

**Confidence:** High - this was the right call for learning and efficiency

##### Insight 2: System Packages > pip for Core Libraries
**Observation:** OpenCV and picamera2 installed via apt were pre-optimized and integrated

**Advantages:**
- Faster installation (pre-compiled ARM binaries)
- Better system integration
- Automatic dependency management
- Official Raspberry Pi Foundation support

**When apt is better:**
- Core libraries (OpenCV, picamera2, NumPy)
- System utilities
- Hardware-specific packages

**When pip is better:**
- Pure Python packages
- Packages not in repositories
- Version-specific requirements

##### Insight 3: Multimeter Validation Prevents Downstream Issues
**Learning:** Testing power rails before connecting components is critical

**What we validated:**
- 3.3V regulator working (protects GPIO)
- 5V rail stable (powers sensors)
- No shorts or power issues

**What this prevents:**
- Damaging expensive cameras ($77)
- Destroying GPIO pins
- Mysterious brownout issues
- Wasted debugging time

**Time investment:** 15 minutes of testing saves hours of troubleshooting

##### Insight 4: Network Configuration More Complex Than Expected
**Complexity Sources:**
- Mesh WiFi systems (Eero)
- Public/Private network settings
- mDNS/Bonjour hostname resolution
- Windows firewall rules

**Resolution Required:**
1. Manual WiFi credentials (auto-detect failed)
2. Network type change (Public → Private)
3. Both steps necessary for robot.local to work

**Lesson:** Budget extra time for network configuration in embedded projects

#### Session Metrics

**Time Breakdown:**
- Hardware validation (multimeter): 30 minutes
- OS installation (two attempts): 40 minutes
- Network troubleshooting: 25 minutes
- System updates: 15 minutes
- OpenCV installation: 12 minutes
- Documentation: 20 minutes
- **Total: ~2.5 hours**

**Accomplishments:** 6 major milestones completed
**Blockers Resolved:** 2 (WiFi auto-detect, network discovery)
**System Status:** Fully operational, ready for camera testing
**Next Session Dependency:** Camera Module 3 (in hand, awaiting connection)

**Success Metrics:**
- ✓ Pi 5 validated healthy (power rails within spec)
- ✓ OS installed and configured
- ✓ SSH access working reliably
- ✓ All libraries installed and verified
- ✓ System ready for Phase 0 Week 2 (camera testing)

#### Next Actions (Session 7 - Camera Connection)

**Immediate Tasks:**
1. Read Camera Module 3 documentation
2. Identify CSI-0 port on Pi 5
3. Insert ribbon cable correctly (blue side orientation)
4. Connect camera securely
5. Test camera detection: `libcamera-hello`
6. Capture first test image

**Week 2 Goals:**
1. Single camera operational
2. Basic picamera2 capture script
3. Port HSV filtering algorithm
4. Measure FPS baseline
5. Install active cooler if thermals require

---

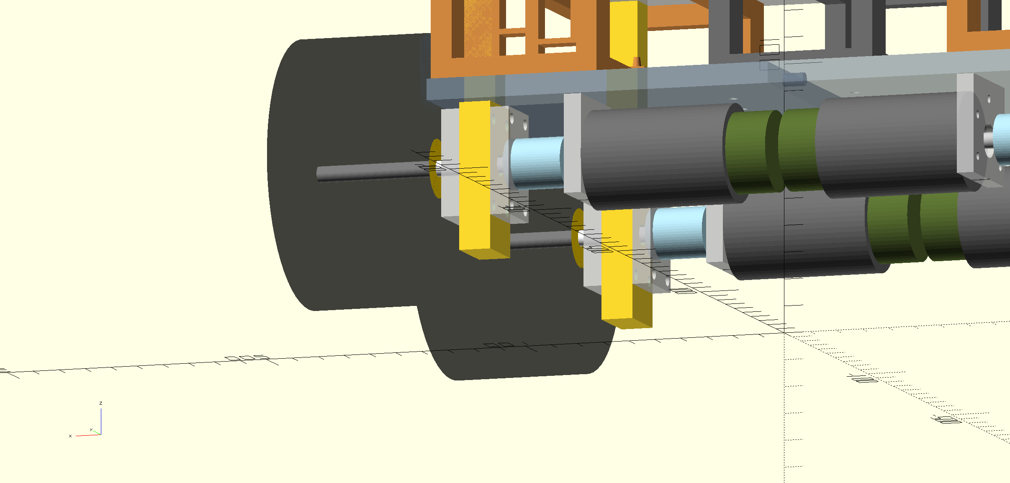
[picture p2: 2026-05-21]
hardware/phase_1/frame00001.png

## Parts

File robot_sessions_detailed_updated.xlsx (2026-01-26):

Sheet: Index
Autonomous Robot Project - Session Tracker
Voice-Controlled Learning Robot | Budget: $2,000 | Open Source Only
Last Updated: December 21, 2025
Phase 0 Status: COMPLETE ✅
Budget: $1,910.54 / $2,000 (95.5%)
Remaining: $89.46
Quick Stats:
• Total Sessions: 7
• Time Invested: ~20 hours
• Hardware Components: 15+
• Major Orders: 3 (all placed Dec 21)
• Next Milestone: Printer arrives Dec 24
Session Overview
# | Date | Duration | Phase | Focus | Spent | Total | Status | Sheet
1-5 | Nov-Dec | ~12h | Planning | Research, parts selection | $462 | $462 | ✅ | → Sessions_1-6
6 | Dec 20 | 2.5h | Phase 0 | OS install, validation | $0 | $462 | ✅ | → Sessions_1-6
7 | Dec 21 | 3h | Phase 0 | Camera, printer, orders | $1,448 | $1,910 | ✅ | → 2025-12-21_18-45
Hardware Procurement Status
Order #111-1218755-5033819 (Amazon): | CORE One Printer - $1,218.43 | Arrives Dec 24 🎄
Order #GE108674O7805NL (Prusa): | 4kg Filament (rPLA+rPETG) - $140.11 | Arrives Dec 25-26 🎅
Order #111-5198911-0120202 (Amazon): | Hardware/Tools (5 items) - $90.00 | Arrives Dec 22-30
Next Milestones
Dec 22: | First tools arrive (calipers, cutters, deburring)
Dec 24: | CORE One printer arrives
Dec 25: | 8-hour printer assembly + filament arrives
Dec 26: | First test prints
Jan 6-12: | Chassis CAD design
Jan 13-19: | Print final chassis in rPETG
Late Jan: | Phase 1 - Motors & wheels

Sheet: Sessions_1-6
Sessions 1-6: Project Foundation & Phase 0 Setup
November - December 20, 2024 | Duration: ~15 hours total
Overview
These sessions established the project foundation, selected all hardware components,
validated the Raspberry Pi 5, and prepared the system for camera integration.
Key Accomplishments (Sessions 1-5: Planning & Procurement)
✅ Project scope defined: Autonomous robot with voice control, computer vision
✅ Hardware platform selected: Raspberry Pi 5 (8GB)
✅ Vision system designed: Dual Camera Module 3 Wide (120° FOV, stereo vision)
✅ Sensors selected: 3× HC-SR04 ultrasonic (obstacle detection)
✅ Power system: Anker PowerCore 20K (26,800mAh battery)
✅ Development tools: Klein MM420 multimeter for validation
✅ Storage: SanDisk Extreme 64GB microSD (A2 rated)
✅ All Phase 0 hardware ordered and delivered by Dec 13
✅ Budget strategy: $2,000 total, open-source software only
✅ Development approach: Voice-controlled learning (no pre-programmed behaviors)
Session 6: OS Installation & Hardware Validation (Dec 20, 2024)
✅ Pi 5 hardware validated with multimeter (3.3V & 5V rails within spec)
✅ Raspberry Pi OS 64-bit installed (Debian Trixie base)
✅ Headless SSH configured (robot.local working via mDNS)
✅ System updates completed (37 packages upgraded)
✅ OpenCV 4.10.0 installed via apt (ARM-optimized)
✅ picamera2 0.3.33 validated (camera library ready)
✅ Network configuration resolved (WiFi + hostname discovery)
✅ Thermal baseline: 39.5°C idle (no active cooler needed yet)
Hardware Inventory (As of Session 6)
Component | Specification | Cost | Status
Raspberry Pi 5 | 8GB RAM, BCM2712 CPU | $80 | ✅ Validated
Camera Module 3 Wide (×2) | 120° FOV, 11.9MP, IMX708 | $82 | ⏳ Ready to connect
HC-SR04 Sensors (×3) | Ultrasonic, 2-400cm range | $12 | ✅ In hand
Anker PowerCore 20K | 26,800mAh, USB-C PD | $52 | ✅ Ready
Klein MM420 Multimeter | Auto-ranging, DC validation | $65 | ✅ Used
SanDisk Extreme 64GB | A2 rated, 160MB/s read | $16 | ✅ OS installed
Official USB-C Power | 27W PD adapter | $12 | ✅ Working
Breadboard & Electronics | Jumpers, logic converter | $20 | ✅ Ready
Networking | Eero mesh WiFi | $71 | ✅ Connected
Key Technical Decisions
• Headless operation: SSH only, no monitor/keyboard (authentic robot deployment)
• Package manager: apt over pip for core libraries (ARM-optimized binaries)
• Network: Manual WiFi credentials (auto-detect failed on mesh network)
• Validation: DC voltage testing before connecting peripherals (prevented damage)
• Camera: Module 3 Wide selected for 120° FOV (stereo vision baseline)
• Budget: Open-source software only, $2,000 hardware cap
Total Spending (Sessions 1-6)
Amount: $462
Budget Remaining: $1,538
Next Steps → Session 7
• Connect Camera Module 3 to Pi 5
• Test camera detection with libcamera
• Research 3D printer for chassis fabrication
• Begin Phase 0 completion (all hardware acquired)

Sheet: 2025-12-21_18-45
Session 7: Camera Setup & 3D Printer Purchase
Date: | December 21, 2025
Duration: | 3 hours
Phase: | Phase 0 - COMPLETE ✅
Focus: | Camera connection, 3D printer research/purchase, complete Phase 0 procurement
Key Accomplishments
✅ Camera Module 3 connected to Pi 5 (defective cable replaced, working)
✅ First test image captured: 4608×2592 resolution, IMX708 sensor validated
✅ CORE One 3D printer ordered ($1,218.43, Amazon, arrives Dec 24)
✅ 4kg recycled filament ordered ($140.11, Prusa Direct, arrives Dec 25-26)
✅ Hardware & tools ordered ($90.00, Amazon, arrives Dec 22-30)
✅ Sustainable materials strategy: rPETG structure + rPLA prototyping
✅ Hybrid design approach: 3D print custom + buy metal standard parts
✅ Phase 0 procurement 100% complete - all orders placed!
Technical Details
Camera Module 3 Connection:
Hardware: | Raspberry Pi Camera Module 3 Wide (120° FOV, 11.9MP, Sony IMX708)
Port: | Pi 5 DISP 1 (upper CSI connector, 22-pin)
Cable: | 22-pin to 15-pin adapter (200mm, included with camera)
Issue: | First ribbon cable defective (camera not detected)
Solution: | Swapped to second included cable - immediately detected as imx708_wide
Orientation: | Blue stripe toward Ethernet (Pi end), away from lens (camera end)
Test: | libcamera-still -o test.jpg --width 4608 --height 2592
Result: | First test image captured successfully - 11.9MP, 30fps capability
3D Printer Selection:
Selected: | Prusa CORE One Kit ($949 + tax = $1,218.43 total)
Design: | CoreXY enclosed (vs traditional bedslinger)
Speed: | 120% faster than MK4S (300mm/s vs 200mm/s)
Build Volume: | 250×220×270mm (30% larger than MK4)
Footprint: | 50% smaller desk space (CoreXY gantry efficiency)
Enclosure: | Full enclosure enables ABS/ASA/Nylon printing (future)
Why vs Bambu Lab: | Open source, serviceable, no vendor lock-in, sufficient speed
Vendor: | Amazon vs Prusa Direct (+$80 premium for 5-week time savings)
Delivery: | December 24, 2025 (vs late January from Czech Republic)
Filament Strategy:
Primary: | rPETG (recycled PETG) - 2kg for structural chassis components
Properties: | Stronger than PLA, heat resistant to 80°C, impact resistant
Cost: | ~$30/kg ($15 premium over virgin PETG)
Secondary: | rPLA (recycled PLA) - 2kg for prototyping, test fits
Properties: | Easy to print, good dimensional accuracy, lower temperature
Cost: | ~$25/kg
Sustainability: | Recycled from plastic bottles (rPETG) and PLA waste (rPLA)
Philosophy: | Design right first, use less material, make durable parts
Hardware & Tools Procured:
Hilitchi 705pc Screw Kit: | $15.99 - M3/M4/M5 stainless steel (arrives Dec 30)
INCLY Heat Set Inserts: | $8.54 - 130pc M3 brass + soldering tip (arrives Dec 28)
HARDELL Digital Calipers: | $22.99 - 6" stainless, 0.001" accuracy (arrives Dec 22)
Hakko Flush Cutters: | $20.65 - 2-pack micro cutters (arrives Dec 22)
AFA Deburring Tool: | $13.99 - Aluminum handle, 11 blades (arrives Dec 22)
Orders Placed
Order # | Vendor | Items | Total | Delivery
111-1218755-5033819 | Amazon | CORE One 3D Printer | $1,218.43 | Dec 24 🎄
GE108674O7805NL | Prusa Direct | 4kg Filament (rPLA+rPETG) | $140.11 | Dec 25-26 🎅
111-5198911-0120202 | Amazon | Hardware/Tools (5 items) | $90.00 | Dec 22-30
Key Decisions Made
• CORE One > MK4S: | 120% faster, enclosed, CoreXY design, 30% larger build, flagship model
• Amazon > Prusa Direct: | $80 premium justified by 5-week time savings (Dec 24 vs late Jan)
• Recycled materials: | rPETG for structure, rPLA for prototyping ($20 sustainability premium)
• Hybrid design: | 3D print custom geometry, buy commercial metal parts (wheels, mounts)
• Skip air filter: | $99 saved - PLA/PETG produce minimal VOCs, enclosure contains particles
• Time value: | Paying premium for immediate delivery maintains project momentum
Problems & Solutions
Problem: Camera not detected:
First ribbon cable was defective. Solution: Swapped to second included cable - worked immediately. Lesson: Always have spare cables for critical components.
Problem: Hardware ASINs out of stock:
2 of 5 planned items unavailable. Solution: Searched for current alternatives, verified each in-stock before ordering. Lesson: Product availability highly dynamic, verify current stock.
Problem: Budget exceeded initial estimate:
CORE One $150 over anticipated MK4. Solution: Justified by speed, enclosure, future-proofing. Lesson: Pay for quality on critical tools, time value matters.
Budget Tracking
Category | Amount | Notes
Prior Sessions (1-6): | $462.00 | Pi 5, cameras, sensors, power, tools, storage
CORE One Printer: | $1,218.43 | Includes $114.28 WA sales tax
Filament (4kg): | $140.11 | Includes $47.99 FedEx shipping + $13.14 tax
Hardware/Tools: | $90.00 | Includes tax on 5 items
Session 7 Total: | $1,448.54
Phase 0 Total: | $1,910.54
Original Budget: | $2,000.00
Remaining: | $89.46 | 4.5% remaining for Phase 1
Next Actions
Immediate (Dec 22-23):
• Download PrusaSlicer: https://www.prusa3d.com/page/prusaslicer_424/
• Watch CORE One assembly video (YouTube: 'Prusa CORE One assembly official')
• Clear workspace on desk (~3×3 feet for assembly)
• Organize tools for assembly
• Read assembly manual: https://help.prusa3d.com/category/core-one_1172
Assembly Day (Dec 24-25):
• Unbox CORE One carefully (photograph parts for reference)
• Inventory all components against packing list
• Follow assembly manual step-by-step (~8 hours)
• Test each subsystem during assembly
• First power-on and self-test calibration
• Load filament (sample Galaxy Black or recycled when arrives)
• First layer calibration (automatic)
• First test print (calibration cube)
Post-Assembly (Dec 26-30):
• Print temperature tower (optimize print settings for rPETG/rPLA)
• Print calibration checkerboard (for camera calibration)
• Print test chassis components (validate design workflow)
• Practice heat-set insert installation (when arrives Dec 28)
• Start chassis CAD design (measure Pi 5, cameras, battery)
Long-term (January):
• Week of Jan 6: Complete chassis CAD design in FreeCAD/Fusion 360
• Week of Jan 13: Print final chassis in rPETG with heat-set inserts
• Week of Jan 20: Assemble chassis, mount Pi 5, cameras, electronics
• Late January: Order Phase 1 components (motors, wheels, driver board)

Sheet: 2026-01-25_OpenSCAD
Session: OpenSCAD Setup & Project Reorganization
January 25, 2026 | Duration: ~4 hours
Overview
Established OpenSCAD development environment, learned CAD design fundamentals for robot chassis development, and reorganized project structure from numbered lessons to topic-based learning directories. Created tutorial progression for 3D design of interlocking robot parts.
Key Accomplishments
✅ OpenSCAD installed on Windows (latest version 2024.11.12)
✅ VS Code OpenSCAD extension configured with auto-update
✅ Dual-screen workflow established (VS Code editing | OpenSCAD preview)
✅ OpenSCAD fundamentals learned: cylinders, cubes, difference operations
✅ Critical concept: clearance tolerances for sliding fits (0.3mm standard)
✅ Peg-in-hole design mastered with proper dimensional accuracy
✅ Understanding of $fn parameter for curve smoothness (60-80 design, 100 export)
✅ Print tolerance concepts: design clearance vs printer accuracy
✅ Project reorganized from src/learning/01-07_topics to topic-based structure
✅ Created learning/ with computer_vision, openscad, machine_learning, etc.
✅ Expanded hardware/ with chassis, camera, sensors, legs, library subdirs
✅ PowerShell migration script created with comprehensive logging
✅ Successfully migrated 17 files with git mv (preserved history)
✅ Created maintenance/ folder for project management scripts
✅ Tutorial files organized: learning/openscad/basics/
Technical Details
OpenSCAD Workflow: Edit .scad files in VS Code → Auto-preview in OpenSCAD app → Export STL → PrusaSlicer
File Resolution: $fn=60-80 for design preview (fast), $fn=100 for final STL export (smooth)
Clearance Standards: Press fit (0.05-0.1mm), Sliding fit (0.2-0.3mm), Loose fit (0.4-0.5mm)
Printer Tolerance: Prusa CORE One ~±0.1-0.2mm XY accuracy (fixed), 0.05-0.3mm layer height (controllable)
Project Structure: learning/ (experiments), src/ (production code), hardware/ (final CAD)
Git Workflow: Used 'git mv' to preserve file history during reorganization
Migration Stats: 20 new directories created, 17 files moved, 0 failures
Files Created
learning/openscad/basics/01_cylinder.scad - Basic shapes introduction
learning/openscad/basics/02_cube_with_holes.scad - Difference operations for mounting holes
learning/openscad/basics/03_wheel.scad - Parametric wheel with weight reduction
learning/openscad/basics/peg_in_hole_example.scad - Interlocking parts with clearance
maintenance/reorganize_folders_1-24-26.ps1 - PowerShell migration script
maintenance/reorganize_log_20260125_052929.txt - Migration execution log
learning_new/ - Complete topic-based directory structure (20 subdirectories)
hardware/chassis, camera, sensors, legs, library, electronics/ - Expanded structure
Next Steps
🔄 Finalize directory reorganization (rename learning_new to learning, remove old structure)
🔄 Commit reorganization to Git with detailed commit message
🔄 Start designing actual robot parts (motor mount, camera bracket, sensor mounts)
🔄 Download Spot Micro STL files for quadruped reference
🔄 Calculate optimal stereo camera baseline spacing (10-20cm range)
🔄 Create parametric chassis base plate in OpenSCAD
🔄 Design wheel motor brackets for Phase 1 wheeled base
🔄 Test print tolerance calibration pieces on Prusa CORE One
Key Learnings
OpenSCAD is code-based CAD - perfect for parametric robot design and version control
Clearance is NOT printer error compensation - it's intentional design gap for part fit
$fn affects visual smoothness only - dimensional accuracy comes from proper measurements
Topic-based organization scales better than numbered lessons for multi-year projects
Git mv preserves file history during reorganization (critical for long-term tracking)
Test prints are essential - design clearance values need real-world validation
Spot Micro chassis can be used with wheels first, then retrofit legs later (hybrid approach)

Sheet: 2026-01-26_Chassis-Design
ROBOT PROJECT SESSION SUMMARY
Date: | 2026-01-26
Session: | OpenSCAD Chassis Design - Vision Test Platform
Duration: | ~2 hours
Focus: | CAD design, OpenSCAD fundamentals, parametric chassis creation
OVERVIEW
Pivoted from exploring existing Spot Micro designs to creating custom parametric OpenSCAD chassis optimized for vision testing. Compared Claude vs Gemini recommendations, verified claims about existing projects (Metabot, OpenCat), and made strategic decision to build purpose-built platform rather than adapt complex existing designs.
KEY ACCOMPLISHMENTS
1. Strategic Decision: Vision-First Approach
- Decided to build minimal test chassis before adding mobility
- Focus on camera mounting and vision algorithms first
- Defer wheel/leg mechanisms until vision system validated
2. Created camera_stereo_bar.scad (Parametric Camera Mount)
- 150mm baseline optimized for 2-400cm detection range
- Exact mounting for Camera Module 3 Wide (120° FOV)
- M2 camera mounting, M3 chassis mounting
- Cable routing channels integrated
- Fully parametric - adjust baseline with single variable
3. Created vision_test_chassis.scad (Complete Test Platform)
- 200×150mm footprint (Spot Micro compatible dimensions)
- 130mm height (cameras at 13cm - optimal for vision)
- Raspberry Pi 5 mounting with standoffs
- Anker PowerCore 20000 battery compartment
- Future Spot leg mounting holes pre-marked
- Weight reduction holes for efficiency
4. Research & Analysis: Compared AI Assistant Recommendations
- Evaluated Claude vs Gemini design approaches
- Verified Gemini's Metabot claim (TRUE - exists with OpenSCAD)
- Debunked "SpotMicro OpenSCAD" claim (FALSE - doesn't exist)
- Analyzed OpenCat (software framework, not CAD files)
5. Learned Critical CAD Workflow Distinctions
- STL import vs parametric design trade-offs
- When to adapt vs build from scratch
- Parametric code advantages over mesh editing
TECHNICAL DETAILS
Camera Configuration:
- Baseline: 150mm (optimal for 50-300cm depth perception)
- Module: Raspberry Pi Camera Module 3 Wide (120° FOV)
- Height: 130mm above ground (good horizon view)
- Mounting: M2 screws, 21mm hole spacing
Chassis Specifications:
- Dimensions: 200×150×130mm (L×W×H)
- Base plate: 3mm PLA
- Struts: 15mm square, 3mm wall thickness, hollow for weight savings
- Pi 5 standoffs: 8mm height for cooling
- Battery pocket: Recessed 1mm for retention
OpenSCAD Design Principles:
- All dimensions parameterized (easy to modify)
- $fn = 60 for preview, increase to 100 for final export
- No supports needed for printing
- Modular design (camera bar separate from chassis)
Print Settings (Prusa CORE One):
- Material: PLA
- Layer height: 0.15-0.2mm
- Infill: 20-30%
- Print time: ~4-6 hours (chassis), ~1 hour (camera bar)
FILES CREATED
1. camera_stereo_bar.scad
- Parametric stereo camera mounting bar
- 420 lines of documented OpenSCAD code
- Includes reference models for visualization
2. vision_test_chassis.scad
- Complete vision test platform
- 520 lines of documented OpenSCAD code
- Component references for Pi5 and battery
KEY DESIGN DECISIONS
Why Parametric from Scratch vs Adapting Existing:
✓ Faster iteration (2 sec preview vs minutes for STL)
✓ Exact fit for specific components (Pi5, Camera Module 3)
✓ Educational value (learn OpenSCAD properly)
✓ Lightweight files (~10KB vs 100MB STL)
✓ Version control friendly (text vs binary)
✗ No pre-validated leg geometry (can add later)
Why Vision-First Approach:
- Camera/vision is project core differentiator
- Can test algorithms on static platform
- Mobility can be added incrementally
- Reduces complexity during learning phase
Why 130mm Camera Height:
- Matches Spot Micro standing height (~13-15cm)
- Good balance of horizon view vs close obstacle detection
- Low enough for stable center of gravity
- High enough to avoid seeing mostly floor
Why 150mm Stereo Baseline:
- Optimal for 50-300cm range (sweet spot for indoor robot)
- Based on stereo vision formula: baseline ≈ 1/10 to 1/20 of max range
- 400cm max detection → 20-40mm baseline range
- 150mm chosen for good all-around performance
KEY LEARNINGS
OpenSCAD Workflow:
- Code-based CAD is ideal for version control and parametric design
- $fn variable controls curve smoothness (not dimensional accuracy)
- Clearances must be designed in (0.2-0.3mm for sliding fits)
- difference() for subtractive features (holes, pockets)
- Modules enable reusable, readable code
AI Assistant Comparison:
- Both can hallucinate, but in different ways
- Gemini initially hallucinated "SpotMicro OpenSCAD" existence
- Gemini correctly identified Metabot (verified via web search)
- Claude initially too dismissive of existing parametric projects
- Both converged on correct recommendation: custom build
Design Philosophy Insights:
- "Box-Dog" concept: simple platform beats premature complexity
- Parametric design pays off even for one-off parts
- Documentation in code is as important as code itself
- Design for current needs, plan for future expansion
NEXT STEPS
Immediate (Next Session):
1. Preview both .scad files in OpenSCAD
2. Verify Camera Module 3 dimensions match specs
3. Export STL files (F6 render, then Export)
4. Slice in PrusaSlicer
5. Print camera bar first (quick test, ~1 hour)
Short Term (1-2 weeks):
1. Print complete chassis
2. Assemble: Pi5 + battery + camera bar
3. Test camera mounting and cable routing
4. Begin stereo vision calibration

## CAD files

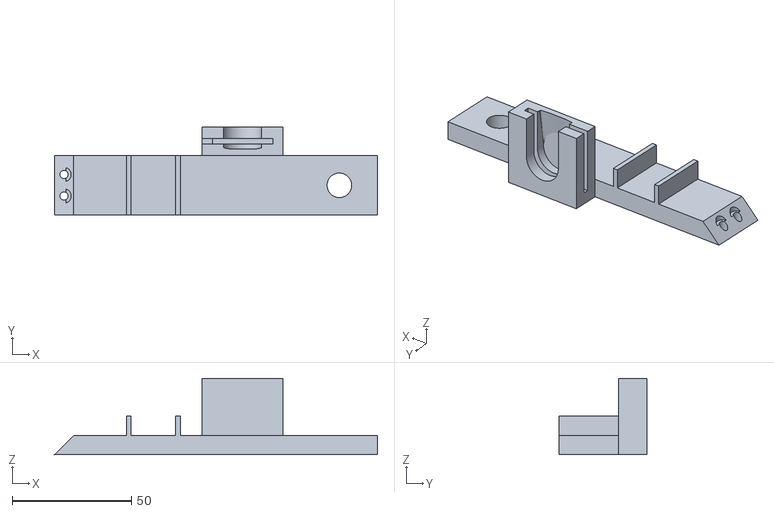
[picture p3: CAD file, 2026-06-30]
hardware/phase_1/camera_bar_r_actual.stl
135.6 x 37.0 x 32.0

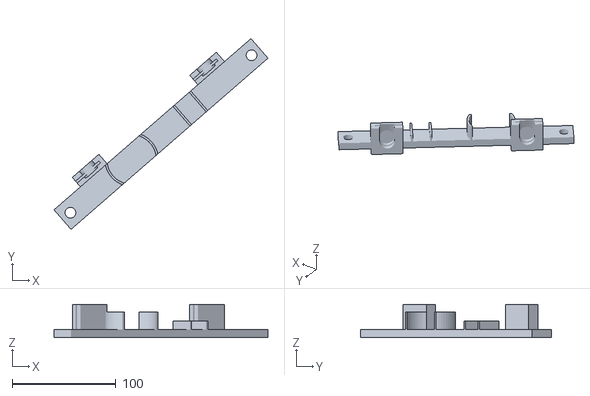
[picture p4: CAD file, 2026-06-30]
hardware/phase_1/camera_bar.stl
206.2 x 183.9 x 32.0

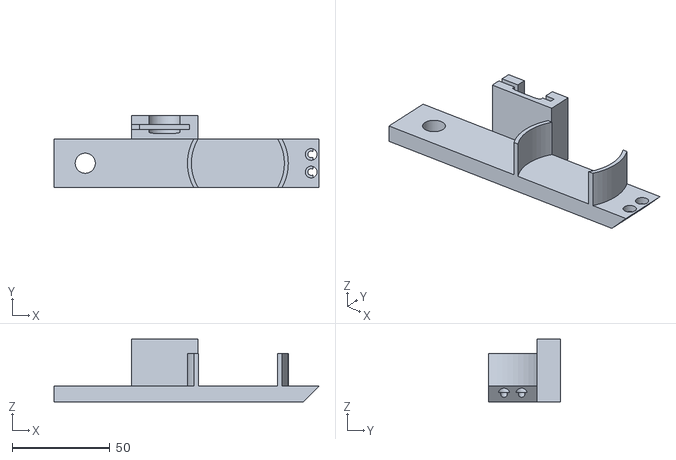
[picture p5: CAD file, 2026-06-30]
hardware/phase_1/camera_bar_r.stl
135.6 x 37.0 x 32.0

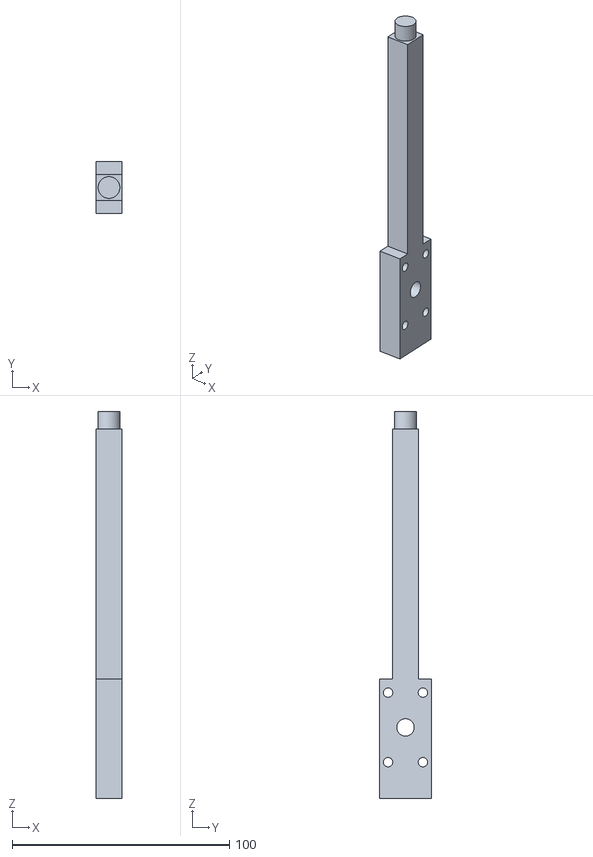
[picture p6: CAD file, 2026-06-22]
hardware/phase_1/leg.stl
12.0 x 24.0 x 178.0

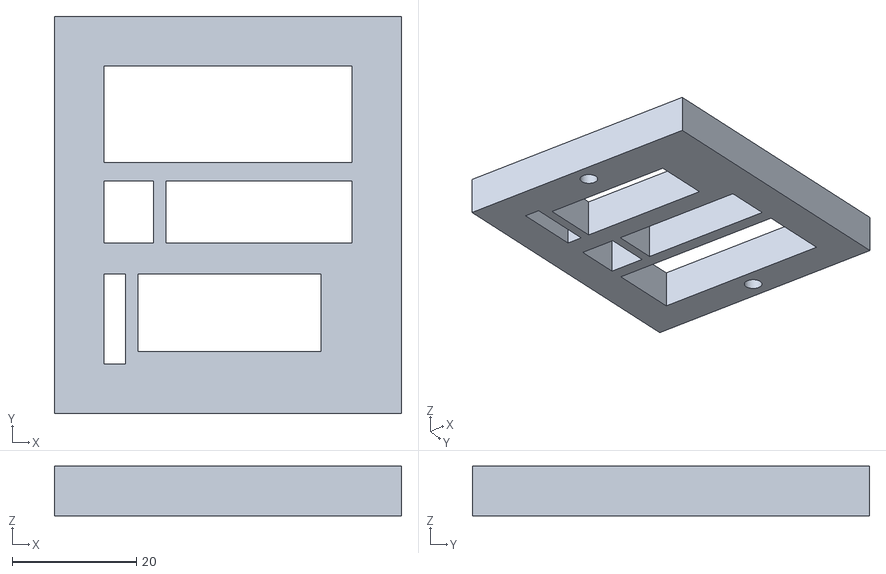
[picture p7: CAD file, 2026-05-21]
hardware/phase_1/side_box_end_switch.stl
56.0 x 64.0 x 8.00

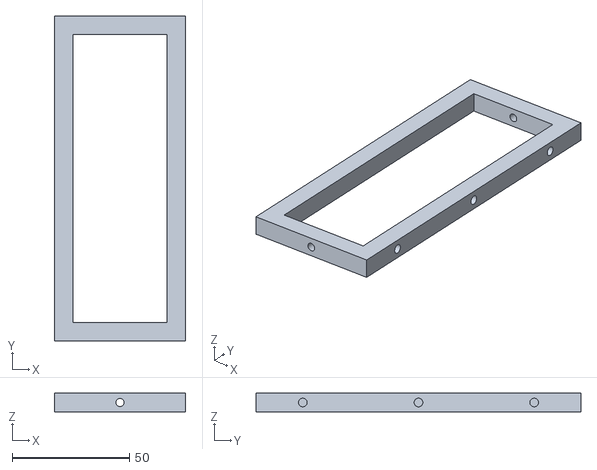
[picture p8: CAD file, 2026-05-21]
hardware/phase_1/battery_box_side.stl
56.0 x 138.8 x 8.00

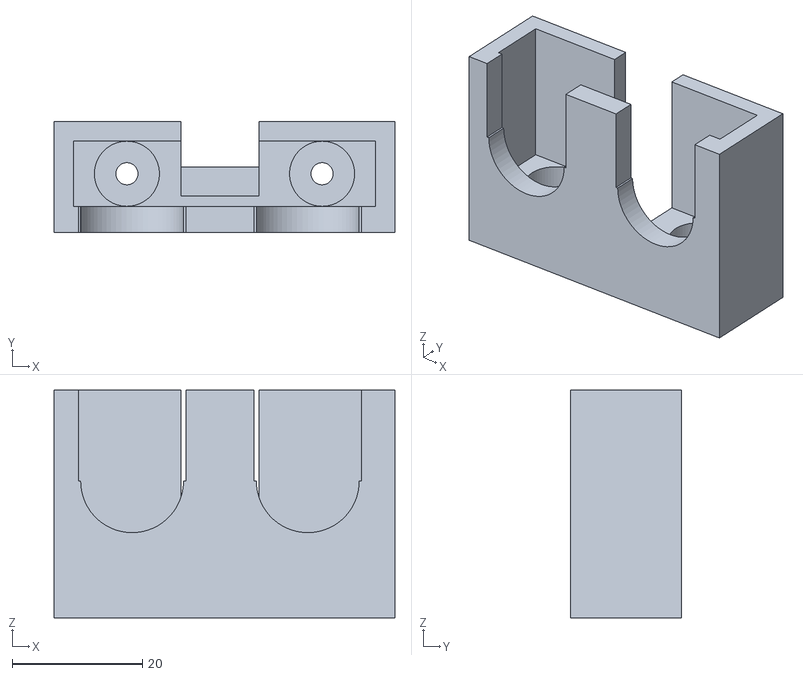
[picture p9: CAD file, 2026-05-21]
hardware/phase_1/sonor_mount.stl
52.4 x 17.0 x 35.0

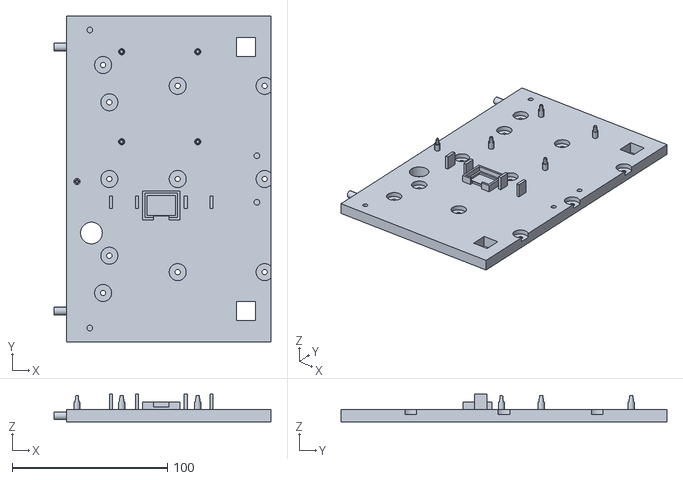
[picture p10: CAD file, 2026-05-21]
hardware/phase_1/top_deck_r.stl
139.6 x 210.0 x 18.0

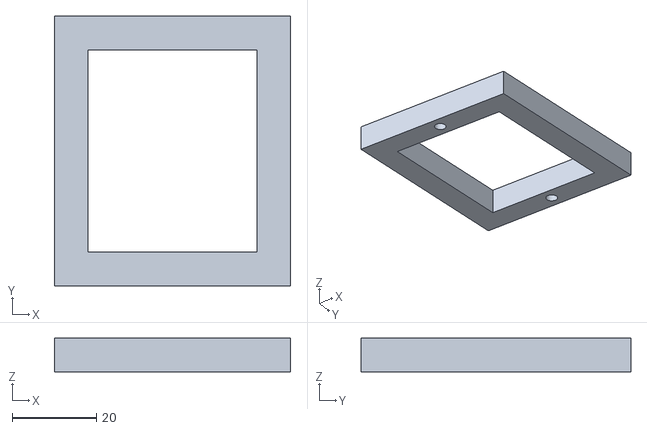
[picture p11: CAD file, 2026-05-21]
hardware/phase_1/side_box_end.stl
56.0 x 64.0 x 8.00

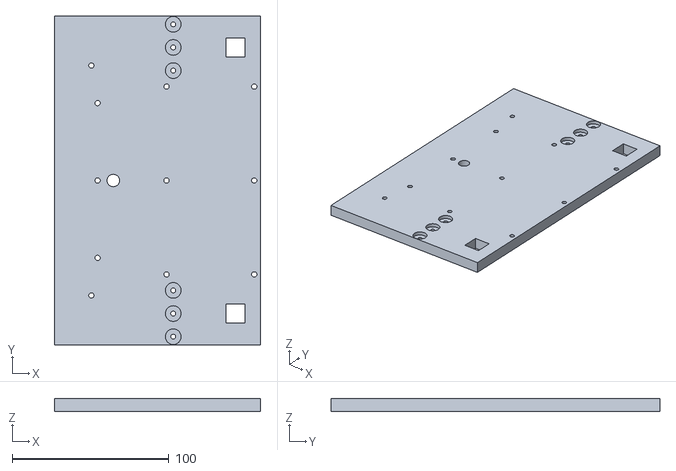
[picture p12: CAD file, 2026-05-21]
hardware/phase_1/bottom_deck_l.stl
131.6 x 210.0 x 8.00

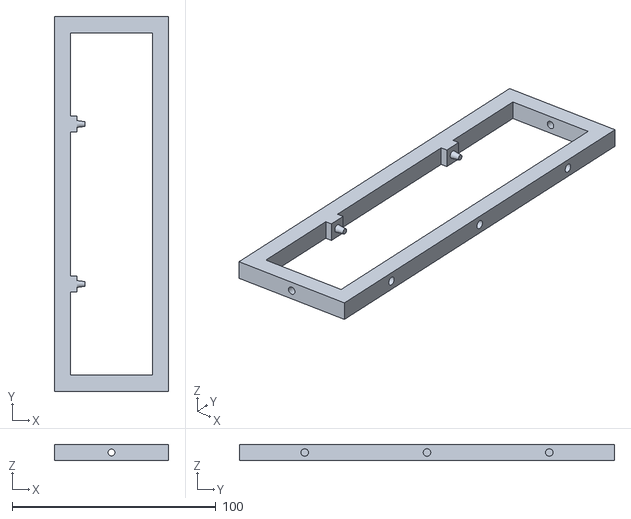
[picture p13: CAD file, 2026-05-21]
hardware/phase_1/side_box_rail.stl
56.0 x 184.0 x 8.00

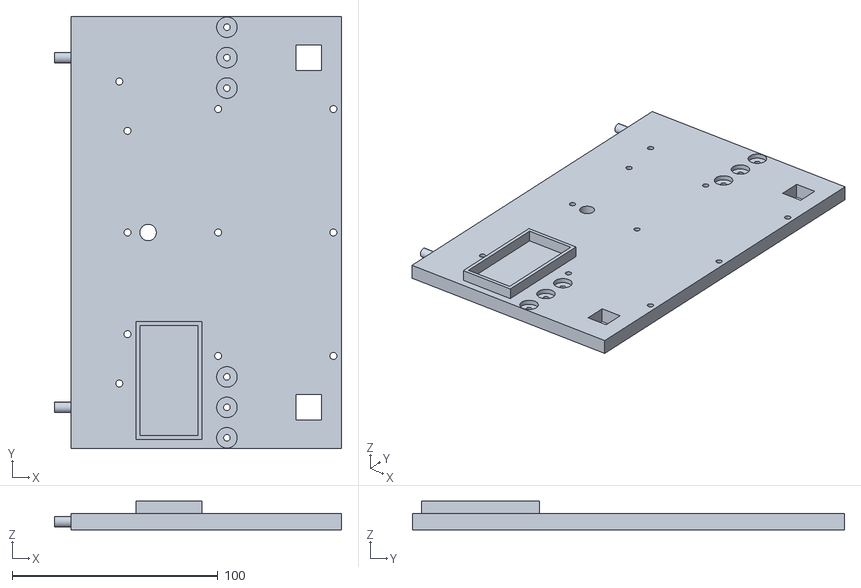
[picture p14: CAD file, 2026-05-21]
hardware/phase_1/bottom_deck_r.stl
139.6 x 210.0 x 14.0

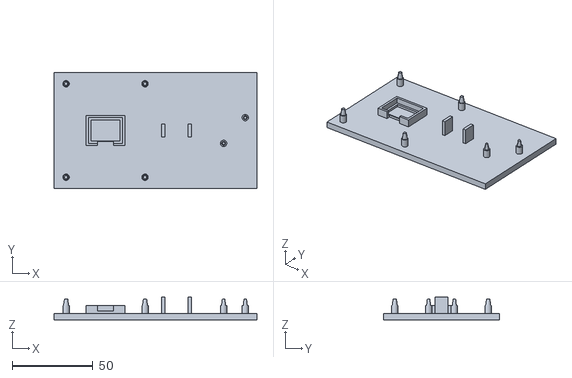
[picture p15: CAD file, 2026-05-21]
hardware/phase_1/test_clip.stl
126.0 x 72.0 x 14.0

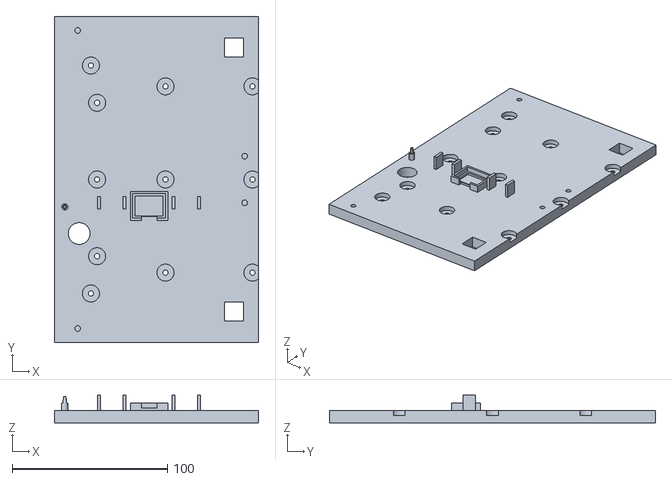
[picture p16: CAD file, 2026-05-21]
hardware/phase_1/top_deck_l.stl
131.6 x 210.0 x 18.0

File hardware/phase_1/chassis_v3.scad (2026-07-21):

// ============================================================================
// TODO — OPEN WORK ITEMS (v3 redesign in progress, July 2026)
// ============================================================================
// Work roughly in order — later items depend on decisions made in earlier ones
// (top deck layout depends on Pi 5 placement, which depends on camera cable
// length; nothing downstream should be finalized before item 1 is validated).
//
// [x] 1a. DIAGNOSIS RESOLVED (Jul 2026, on real hardware).
//        Pi1 (old board): CONFIRMED FAULTY. Cardless, powered buck→GPIO
//          2/4/6, a USB stick showed ZERO response — a hardware fault on
//          Pi1 itself (probably related to whatever also broke its camera
//          connector), NOT the generic Pi5 GPIO-power behavior being
//          investigated below. Settled — Pi1 is retired as a test board and
//          as the robot's compute board (already being replaced by Pi2
//          regardless, per item 16a).
//        Pi2 (new 8GB board): cardless, same power method, the stick blinked
//          fine. With an OS booted and the SPEAKER plugged in (but never
//          switched on), `lsusb` showed nothing and the charge LED stayed
//          dark — looked like a current/enumeration limit. Tried the free
//          software fix (`usb_max_current_enable=1` + EEPROM
//          `PSU_MAX_CURRENT=5000`, full power cycle) — speaker still didn't
//          show up. But swapping in the USB stick in that same state
//          enumerated cleanly, which broke the "ports are broken" theory.
//        ROOT CAUSE: the speaker's power button had never been pressed —
//          every prior observation was its passive charging behavior, not a
//          failed USB enumeration attempt. Once switched to "PC mode" via
//          its button, it enumerated immediately (`lsusb`: "ID 8087:1024
//          Intel Corp. USB2.0 Device"). This was never a Pi 5 power-scheme
//          problem — plain buck→GPIO 2/4/6 power is sufficient for Pi2's
//          USB-A ports with the devices tested so far (stick + speaker,
//          individually).
//        CONFIRMED with a real combined-load test: mic + speaker plugged in
//          SIMULTANEOUSLY (via extension cables to fit both), both showed in
//          `lsusb` (card 2 "USB PnP Sound Device" mic, card 3 "USB2.0
//          Device" speaker). Recorded 5s with `arecord -D plughw:2,0 ...`,
//          played back with `aplay -D plughw:3,0 test.wav` — clean full
//          loop, played back loud and clear. Plain buck→GPIO 2/4/6 power
//          handles mic+speaker together with no issue.
//
// [ ] 1b. USB-C POWER INJECTOR — DEFERRED, not proven necessary. Do NOT
//        build this speculatively; item 1a's original justification for it
//        (ports broadly non-functional) turned out to be a false alarm.
//        Only revisit if a real higher cumulative-load test (e.g. mic +
//        speaker + cameras + AI HAT all active at once, once the HAT is
//        installed) actually shows a current/brownout problem plain GPIO
//        power can't handle. If that happens, this is the assembly plan:
//        - Adafruit #4090 breakout (item 13a). Solder one leg of each of the
//          2× 5.1kΩ resistors (item 13b) into the CC1 pad and the CC2 pad.
//        - The OTHER leg of both resistors joins a 4-way splice: a 22AWG GND
//          pigtail soldered into the board's GND pad, plus the buck's GND
//          lead. Pre-tin all four leads, twist, solder, slide on heat shrink
//          BEFORE soldering (easy to forget), shrink it down, then anchor the
//          splice near the board (hot glue or a zip-tie) so cable weight/
//          vibration can't pull on the thin resistor legs at the CC1/CC2 pads.
//        - Buck's +5V lead → VBUS pad. Leave D+, D-, SBU1, SBU2 unconnected
//          (power-only; no USB data over this port).
//        - Bridge the 4090's onboard female receptacle to the Pi 5's USB-C
//          port with the 6" USB-C-to-USB-C cable (ordered). Anchor both cable
//          ends (zip-tie/hot-glue right at the jacket-to-plug transition) so
//          vibration strain lands on the anchor, not the solder joints.
//        BEFORE connecting to Pi2: verify with a multimeter — no VBUS–GND
//        short, and ~5.1kΩ reading from each of CC1 and CC2 to GND.
//        Then power up on Pi2 (the software-only fix is already ruled out —
//        see 1a) and confirm `lsusb` shows the speaker and the USB-A ports
//        activate at full current instead of staying limited.
//        Still open: buck sizing (see item 13 note) — the combined 5V-rail
//        worst-case load is already at/over the D24V50F5's 5A rating now that
//        the AI HAT is in the picture; revisit once this test confirms the
//        wiring scheme itself works.
//
// [ ] 2. POWER SUFFICIENCY TEST — incrementally add every device to Pi2 and
//        confirm operability BEFORE buying/installing the AI HAT+2 (item 3).
//        Isolates any power problems to the current known configuration
//        instead of conflating them with the HAT's much larger draw once
//        it's added. Build up from what's already confirmed (see item 1a):
//        - [x] USB devices — mic + speaker simultaneously, confirmed working
//          (item 1a: clean record/playback loop, both enumerated together).
//        - [x] Motors + encoders + cooler — CONFIRMED (Jul 2026) via a
//          combined Python test (gpiozero): CPU load forced whenever SoC
//          temp < 65C (cooler audibly kicks on, confirms fan works without
//          the adhesive thermal pad), each of the 4 wheels spun exactly one
//          encoder-counted revolution (3200 counts = 64 CPR x 50:1 gearbox,
//          confirms PWM/DIR signal integrity AND encoder wiring together),
//          and the mic/speaker record-playback loop re-verified clean with
//          all of the above running simultaneously. No Pi brownout/reset,
//          no audio glitches. Wire colors used: DIR=orange, PWM=red,
//          GND=black (motors); native colors + ganged blue/green (encoders)
//          — see PIN ASSIGNMENTS section.
//        - [ ] + Cameras — 2× Camera Module 3 Wide. Stock CSI cable should be
//          fine for this bench test (Pi2 isn't in its final mounted position
//          yet — the 300mm/500mm cable need from item 4 is specifically for
//          the final chassis position, not this test). Confirm both
//          initialize (`rpicam-hello --list-cameras`) without instability
//          while USB devices + motors stay in the mix.
//        - [ ] + Ultrasonic sensors — HC-SR04 × 4 through the LC757 level
//          shifters. Confirm clean readings with everything else running,
//          especially watching for voltage-droop-induced misreads while
//          motors are active at the same time.
//        Only once ALL of the above are confirmed stable together: move to
//        item 3 (buy/assemble the AI HAT+2) — adding the biggest single
//        power draw in the system on top of an already-validated baseline,
//        instead of on top of unknowns.
//
// [ ] 3. PI 5 + AI HAT STACK — buy, assemble, measure. Real numbers from this
//        physical stack are a prerequisite for item 4 (top deck redesign) —
//        don't guess dimensions there when they can be measured here first.
//        Buy remaining parts:
//        - Raspberry Pi 5 (8GB), new (item 16a).
//        - Raspberry Pi AI HAT+ 2 / Hailo-10H (item 16b).
//        - Taller GPIO stacking header — the AI HAT+2's stock header leaves no
//          usable pin length above the HAT for the Dupont sensor/motor
//          connections (confirmed — stock pins sit flush with the HAT top).
//          Still unsourced; find one long enough to clear the Active Cooler
//          gap AND leave enough exposed pin above the HAT for a secure Dupont
//          connection.
//        - Active Cooler already on hand.
//        Assemble: Pi 5 + Active Cooler + stacking header + AI HAT+2 + its own
//        bundled heatsink, per Raspberry Pi's official stacking instructions.
//        Measure once assembled:
//        - Total stack height, Pi 5 board bottom to top of the AI HAT+2's
//          heatsink — sets TOTAL_HEIGHT (currently a placeholder).
//        - Exposed GPIO pin length above the HAT with the new header — confirm
//          it's enough for a secure Dupont connection.
//        - Footprint and connector positions relative to the Pi 5 board edges
//          (USB-C power port + item 13a assembly, 2× USB-A, Ethernet, camera
//          connectors, power button) — feeds directly into item 4's
//          connector-clearance requirement.
//
// [ ] 4. TOP DECK REDESIGN (both halves) — replace the tapered friction-fit
//        standoff pins (breaking/fragile in practice) with a new Pi 5
//        retention method:
//        - Leading option: friction-fit walls around the board edges, routed
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

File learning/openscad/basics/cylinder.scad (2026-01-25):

// Peg-in-Hole Example: Cylinder slides into Cube
// This demonstrates clearance for interlocking parts

$fn = 80                                  ;  // Smooth preview

// === DESIGN PARAMETERS ===

// The peg (cylinder) dimensions
peg_diameter = 10.0;   // 10mm cylinder that will slide into hole
peg_height = 25;       // 25mm tall

// Clearance for sliding fit
sliding_clearance = 0.1;  // 0.3mm gap (0.15mm per side)

// Calculate hole size (needs to be bigger than peg!)
hole_diameter = peg_diameter + sliding_clearance;
// Result: 10.3mm hole for 10.0mm peg


// === PART 1: THE CUBE WITH HOLE ===

difference() {
    // Main cube
    cube([40, 40, 15]);  // 40mm × 40mm × 15mm tall
    
    // Hole for cylinder to slide into
    // Position hole at center of cube
    translate([20, 20, -1])  // Center: half of 40mm, half of 40mm
        cylinder(h=17, r=hole_diameter/2);  // 10.3mm diameter hole
}


// === PART 2: THE CYLINDER PEG ===

// Position it next to the cube so you can see both parts
translate([50, 20, 0]) {  // Move it 50mm to the right
    
    color("lightblue")  // Color it so it's easy to distinguish
        cylinder(h=peg_height, r=peg_diameter/2);  // Exact 10.0mm peg
}


// === PART 3: ASSEMBLED VIEW ===

// Show how they fit together (further to the right)
translate([100, 0, 0]) {  // Move assembly 100mm right
    
    // The cube with hole
    difference() {
        cube([40, 40, 15]);
        translate([20, 20, -1])
            cylinder(h=17, r=hole_diameter/2);
    }
    
    // The peg inserted into the hole
    translate([20, 20, 0])  // Position at hole center
        color("lightblue")
            cylinder(h=peg_height, r=peg_diameter/2);
    
    // Note: Peg sticks out 10mm above cube (25mm - 15mm)
}


// === VISUAL GUIDE ===

// Add text labels (these won't print, just for visualization)
translate([5, -5, 0])
    color("black")
        text("Cube with Hole", size=4);

translate([50, -5, 0])
    color("black")
        text("Cylinder Peg", size=4);

translate([100, -5, 0])
    color("black")
        text("Assembled", size=4);


// === MEASUREMENTS ===
// Peg diameter: 10.0mm
// Hole diameter: 10.3mm
// Clearance: 0.3mm total (0.15mm gap on each side)
// 
// This 0.3mm clearance allows:
// - Smooth sliding assembly
// - Accounts for printer tolerance (±0.1mm)
// - No binding or forcing needed


// === EXERCISES ===
// 1. Change sliding_clearance to 0.1 - tighter fit
// 2. Change sliding_clearance to 0.5 - looser fit  
// 3. Change peg_diameter to 8.0 - everything scales!
// 4. Make peg_height = 12 to see it NOT stick out above cube

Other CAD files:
hardware/phase_1/battery_box_end.stl

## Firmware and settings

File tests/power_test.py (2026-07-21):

#!/usr/bin/env python3
"""Combined power/functionality test: cooler (via CPU load), wheels, mic/speaker."""

import time
import subprocess
import multiprocessing
from gpiozero import PWMOutputDevice, DigitalOutputDevice, DigitalInputDevice

MOTORS = {
    "mtr_r_f": {"pwm": 18, "dir": 23, "enc_a": 5},
    "mtr_r_b": {"pwm": 19, "dir": 24, "enc_a": 25},
    "mtr_l_f": {"pwm": 12, "dir": 17, "enc_a": 20},
    "mtr_l_b": {"pwm": 13, "dir": 27, "enc_a": 16},
}

COUNTS_PER_REV = 3200   # Pololu 37D: 64 CPR motor shaft x 50:1 gearbox
SPIN_DUTY = 0.45        # moderate speed -- keeps encoder pulse rate trackable
TEMP_THRESHOLD_C = 65.0

def get_temp_c():
    with open("/sys/class/thermal/thermal_zone0/temp") as f:
        return int(f.read().strip()) / 1000.0

def _burn(seconds):
    end = time.time() + seconds
    while time.time() < end:
        pass

def stress_cpu(seconds=3, workers=4):
    procs = [multiprocessing.Process(target=_burn, args=(seconds,)) for _ in range(workers)]
    for p in procs:
        p.start()
    for p in procs:
        p.join()

def spin_one_revolution(name, pins):
    pwm = PWMOutputDevice(pins["pwm"])
    direction = DigitalOutputDevice(pins["dir"])
    encoder = DigitalInputDevice(pins["enc_a"])

    count = 0
    def _tick():
        nonlocal count
        count += 1
    encoder.when_activated = _tick

    direction.off()
    pwm.value = SPIN_DUTY
    print(f"  {name}: spinning...")
    start = time.time()
    while count < COUNTS_PER_REV:
        time.sleep(0.01)
        if time.time() - start > 10:
            print(f"  {name}: WARNING - timed out ({count}/{COUNTS_PER_REV} counts) "
                  f"- check encoder wiring/pin")
            break
    pwm.off()
    print(f"  {name}: done ({count} counts)")

    pwm.close()
    direction.close()
    encoder.close()

def record_and_playback():
    input("Press Enter, then speak your message (recording starts immediately)...")
    print("Recording 5s...")
    subprocess.run(["arecord", "-D", "plughw:2,0", "-d", "5", "-f", "cd", "-t", "wav", "test.wav"])
    print("Playing back...")
    subprocess.run(["aplay", "-D", "plughw:3,0", "test.wav"])

def main():
    print("Combined power/functionality test running. Ctrl+C to stop.")
    try:
        while True:
            temp = get_temp_c()
            print(f"SoC temp: {temp:.1f}C")
            if temp < TEMP_THRESHOLD_C:
                print("  Below threshold - forcing CPU load...")
                stress_cpu()
            else:
                print("  At/above threshold - skipping CPU load this pass.")

            for name, pins in MOTORS.items():
                spin_one_revolution(name, pins)

            record_and_playback()
            print("--- pass complete ---\n")
    except KeyboardInterrupt:
        print("\nStopped.")

if __name__ == "__main__":
    main()

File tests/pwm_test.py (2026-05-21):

#!/usr/bin/env python3
"""
MDD10A PWM test — single channel
Pi GPIO 18 → MDD PWM1
Pi GPIO 23 → MDD DIR1
Pi GND     → MDD GND
"""

from gpiozero import PWMOutputDevice, DigitalOutputDevice
from time import sleep

PWM_PIN = 18
DIR_PIN = 23
PWM_FREQ = 1000  # 1 kHz

pwm = PWMOutputDevice(PWM_PIN, frequency=PWM_FREQ)
dir = DigitalOutputDevice(DIR_PIN)

try:
    print("Setting DIR=HIGH (forward)")
    dir.on()

    input("Press Enter to set PWM=0% (motor stopped)...")
    pwm.value = 0.0
    print(f"PWM duty: {pwm.value*100:.0f}%")

    input("Press Enter to set PWM=50%...")
    pwm.value = 0.5
    print(f"PWM duty: {pwm.value*100:.0f}%")

    input("Press Enter to set PWM=100% (full speed)...")
    pwm.value = 1.0
    print(f"PWM duty: {pwm.value*100:.0f}%")

    input("Press Enter to flip DIR=LOW (reverse) at 50%...")
    pwm.value = 0.5
    dir.off()
    print(f"DIR: LOW, PWM duty: {pwm.value*100:.0f}%")

    input("Press Enter to stop and exit...")
    pwm.value = 0.0
    print("Stopped.")

finally:
    pwm.close()
    dir.close()
    print("GPIO released.")

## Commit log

2025-12-22 session 12-21b
    [robot_sessions_detailed.xlsx]
2026-01-25 sessionn 1-25-26
    [cylinder.scad, robot_sessions_detailed_updated.xlsx]
2026-01-26 lesson 1-25-26
    [camera_stereo_bar.scad, robot_sessions_detailed_updated.xlsx, vision_test_chassis.scad]
2026-01-27 phase 1
    [assembly_visualization.scad, design2.scad, vision_test_chassis.scad]
2026-01-27 phase 1.1
    [assembly_visualization.scad, camera_stereo_bar.scad, design.scad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]
2026-02-21 Add dual-deck mecanum chassis design (v2.2)
    Adds chassis_gemini.scad (original reference) and chassis_v2.scad,
    a cleaned-up redesign of the dual-deck learning robot platform with:
    - All magic numbers replaced with named, commented parameters
    - Modular deck_plate, corner_leg, drivetrain_stack, mecanum_wheel modules
    - Fixed ground clearance bug (axle was 13.5mm underground)
    - Raised deck heights: bottom 55→75mm, top 100→120mm, total 160→180mm
    - Corrected drivetrain dims to real Pololu 37D and Studica mecanum specs
    - Proper mecanum wheel visualization with 9 rollers at 45deg per corner
    - Correct left/right slant assignment per corner for holonomic motion
    - Battery tray, M3 mounting hole g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
    [chassis_gemini.scad, chassis_v2.scad]
2026-03-01 2-28-26 cleanup
    [chassis_v2.scad, wheel.scad]
2026-03-01 2-28-26 motor
    [chassis_v2.scad]
2026-06-30 device tests
2026-07-21 power testing
    [chassis_v3.scad]
2026-10-13 claude, open and wheel test
2026-10-13 change wiring
